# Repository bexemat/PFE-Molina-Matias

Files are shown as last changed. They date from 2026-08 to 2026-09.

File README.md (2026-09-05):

# Proyecto Final de Estudios (PFE) - Ingeniería en Mecatrónica (UNCUYO)

### Integración de Sistema de Visión Artificial y Planificación Dinámica de Trayectorias para una Celda de Clasificación Pick-and-Place

* **Autor:** Matías Exequiel Molina
* **Director:** Eric Sanchez
* **Institución:** Universidad Nacional de Cuyo - Facultad de Ingeniería
* **Año:** 2026

---

## 📌 Resumen del Proyecto

Este trabajo constituye una evolución técnica y funcional del manipulador paralelo de 3 GDL desarrollado previamente por Agüero y Lezcano. Transforma una maqueta experimental estática en una celda de manufactura orientada a estándares industriales, capaz de interceptar y clasificar piezas en movimiento continuo sobre una cinta transportadora mediante visión artificial en tiempo real y arquitectura de software distribuida.

### Puntos Clave de la Reingeniería
* **Control Embebido Determinista (Firmware C / FreeRTOS):** Migración de la cinemática inversa analítica y del planificador de trayectorias quínticas ($C^2$) hacia la FPU del microcontrolador STM32F446RE, desacoplando el lazo de control del tráfico serial en ROS 2. Lazo de movimiento determinista a 100 Hz (`mControlTask`) con PWM generado por hardware (TIM2, TIM3, TIM13) y lectura de encoders magnéticos absolutos AS5600 (12 bits) vía I2C a 400 kHz con multiplexor TCA9548A.
* **Percepción Visual en Tiempo Real (ROS 2 / OpenCV):** Estimación determinista de la velocidad lineal de avance mediante compuertas espaciales fijas ($\Delta Y = 70.0\text{ mm}$) a 30 FPS. Clasificación geométrica de piezas (Cubo vs. Cono) invariante a la rotación mediante el análisis combinado de *Extent* y relación de envolventes (*Rect Ratio*).
* **Supervisión y Orquestación:** Máquina de estados en ROS 2 con compensación temporal de magnetización ($T_{anticipo} = 0.15\text{ s}$), verificación en lazo cerrado de posición de reposo ($\pm2.0\text{ mm}$), despegue vertical puro ($Z_{lift} = 125.0\text{ mm}$) para suprimir fuerzas cortantes y retorno rápido evasivo ante fallos de retención.
* **Mecánica y Hardware:** Unión por chavetero mecanizada en los ejes de los motores paso a paso y engranajes impresos en 3D para neutralizar holguras y deslizamiento torsional. Acondicionamiento de pares trenzados blindados en el bus I2C (SCL/GND y SDA/VCC) para suprimir interferencias electromagnéticas. Integración de una cinta transportadora a escala diseñada en CAD (SolidWorks).

---

## 🛠️ Especificaciones Técnicas

* **Sistema Operativo:** Ubuntu 22.04 LTS (Jammy Jellyfish)
* **Middleware Robótico:** ROS 2 Humble Hawksbill & micro-ROS (XRCE-DDS serial @ 115200 baudios)
* **Herramientas de Firmware:** STM32CubeIDE v1.14+, FreeRTOS v10.3, ARM GCC Toolchain
* **Hardware de Control:** STM32 Nucleo-F446RE, 3x Controladores Pololu DRV8825 (configurados a 1/8 de micropaso)
* **Sensores:** 3x Encoders magnéticos absolutos de 12 bits AS5600 (I2C @ 400 kHz), Multiplexor TCA9548A
* **Visión:** Cámara Cenital HD 720p @ 30 FPS conectada mediante symlink persistente V4L2

---

## 📁 Estructura del Repositorio

```text
robot_workspace/
├── Firmware/                      # Proyecto STM32CubeIDE (C / FreeRTOS / micro-ROS)
│   ├── Core/
│   │   ├── Inc/                   # kinematics.h, trajectory_planner.h, motors.h, main.h, etc.
│   │   └── Src/                   # kinematics.c, trajectory_planner.c, tasks.c, main.c, etc.
│   └── micro_ros_stm32cubemx_utils/
├── ros2_ws/                       # Workspace de ROS 2 Humble
│   └── src/
│       ├── extra_interfaces/      # Mensajes personalizados ROS 2 (Trama.msg)
│       ├── robot_bringup/         # Archivos de lanzamiento consolidado (robot.launch.py)
│       └── robot_control/         # Paquete de control, visión y GUI
│           ├── gui/               # Interfaz V1 (robot_ui_node) y widgets Matplotlib
│           ├── gui_pickAndPlace_Final/ # Interfaz V2 continua (robot_ui_node_2) y FSM
│           ├── orchestrator/      # Nodo puente orquestador (publisher.py)
│           ├── planning/          # Herramientas auxiliares de planificación
│           └── vision/            # Nodo de visión OpenCV y scripts de calibración
├── Informe/                       # Documento formal del PFE en LaTeX (.tex) y bibliografía (.bib)
└── README.md

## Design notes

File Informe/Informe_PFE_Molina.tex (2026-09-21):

\documentclass[12pt, a4paper]{report}

% Paquetes esenciales
\usepackage[utf8]{inputenc}
\usepackage[spanish, es-tabla, es-nodecimaldot, es-noshorthands]{babel}
\usepackage[T1]{fontenc}
\usepackage{graphicx}
\usepackage{amsmath, amssymb}
\usepackage{booktabs}
\usepackage{tabularx}
\usepackage{geometry}
\geometry{top=3cm, bottom=3cm, left=3cm, right=3cm}

% Manejo de enlaces y corte de URLs sin desbordar margen
\PassOptionsToPackage{hyphens}{url}
\usepackage{hyperref}
\hypersetup{
    breaklinks=true,
    colorlinks=true,
    linkcolor=primary,
    citecolor=secondary,
    urlcolor=accentblue
}

% Paquetes para evitar desbordes de margen (Overfull \hbox)
\usepackage{microtype}
\usepackage[htt]{hyphenat}

\usepackage{titlesec}
\usepackage{fancyhdr}
\usepackage{cite}
\usepackage{float}
\usepackage{subcaption}
\usepackage{tikz}
\usepackage{pgfplots}
\pgfplotsset{compat=1.18}
\usepackage{array}
\usepackage{xcolor}
\usetikzlibrary{calc, babel, shapes.geometric, arrows.meta, positioning, fit, backgrounds, shadows}

% Definición de paleta de colores institucional
\definecolor{primary}{RGB}{24, 43, 73}
\definecolor{secondary}{RGB}{70, 130, 180}
\definecolor{lightgray}{RGB}{248, 249, 251}
\definecolor{darkgray}{RGB}{50, 50, 50}
\definecolor{accentblue}{RGB}{2, 136, 209}
\definecolor{accentorange}{RGB}{245, 124, 0}
\definecolor{accentpurple}{RGB}{81, 45, 168}
\definecolor{accentgreen}{RGB}{56, 142, 60}
\definecolor{accentred}{RGB}{198, 40, 40}

% Estilo de títulos
\titleformat{\chapter}{\normalfont\huge\bfseries}{\thechapter.}{20pt}{\Huge}

\title{Integración de Sistema de Visión Artificial y Planificación Dinámica de Trayectorias para una Celda de Clasificación Pick-and-Place sobre una Plataforma Robótica Existente}
\author{Matías Exequiel Molina}
\date{2026}

\begin{document}

\begin{titlepage}
    \centering
    \vspace*{1cm}
    \Large Universidad Nacional de Cuyo \\
    \large Facultad de Ingeniería \\
    \vspace{1cm}
    \Huge \textbf{Proyecto Final de Estudios} \\
    \vspace{0.5cm}
    \large Ingeniería en Mecatrónica \\
    \vspace{2cm}
    \Huge \textbf{Integración de Sistema de Visión Artificial y Planificación Dinámica de Trayectorias} \\
    \vspace{1cm}
    \large \textit{Continuación y evolución del sistema robótico de Agüero y Lezcano} \\
    \vspace{2cm}
    \textbf{Alumno:} Matías Exequiel Molina \\
    \textbf{Director:} Eric Sanchez \\
    \vspace{2cm}
    Mendoza, Argentina \\
    2026
\end{titlepage}

% ==========================================
% 2ª CARILLA: RESUMEN / ABSTRACT
% ==========================================
\newpage
\thispagestyle{plain}
\begin{center}
    \vspace*{0.5cm}
    {\Large \textbf{Resumen}}
    \vspace{0.8cm}
\end{center}

El presente Proyecto Final de Estudios aborda la evolución, reingeniería e integración funcional de una celda de manufactura robotizada a escala para operaciones de clasificación tipo \textit{pick-and-place} dinámico sobre piezas en movimiento. Tomando como plataforma de partida un manipulador serial de 3 GDL con mecanismo de paralelogramo articulado de cuatro barras desarrollado en un proyecto precedente, se diseñó e incorporó una cinta transportadora motorizada independiente y se transformó la operación estática original en un lazo continuo gobernado por visión artificial y control embebido determinista.

Para superar las restricciones de la plataforma heredada, se llevó a cabo una intervención integral a nivel mecánico, electrónico y computacional. En el aspecto físico, se implementaron acoples con unión por chaveta mecanizada en los ejes motores y un esquema de par trenzado diferencial para restaurar la integridad del bus I2C de los encoders magnéticos AS5600. En el plano cinemático, se descartó el modelo previo basado en articulaciones virtuales de Denavit-Hartenberg, formulando una cinemática inversa geométrica directa libre de singularidades espaciales. Asimismo, se reestructuró la arquitectura de control migrando el cálculo analítico de trayectorias quínticas ($C^2$) y el lazo de velocidad \textit{feedforward} + P a 100~Hz directamente a la FPU del microcontrolador STM32F446RE bajo FreeRTOS, comunicándose mediante micro-ROS con el host de supervisión y una nueva interfaz gráfica interactiva en PyQt5.

La percepción cenital en OpenCV (30~FPS, espacio HSV) introduce un esquema de compuertas espaciales consecutivas sobre la cinta que estima la velocidad lineal de avance en tiempo real ($v_{\text{obj}}$) sin depender de la carga gráfica del supervisor, complementado con un algoritmo de discriminación geométrica invariante a la orientación (Cubo vs. Cono) mediante la relación de envolventes (\textit{Rect Ratio}). Un filtro analítico de factibilidad cinemática evalúa en tiempo de ejecución si el tiempo disponible de arribo satisface los límites dinámicos de aceleración del robot ($T_{\text{MIN\_ROBOT}}$), sincronizando la intercepción mediante una rutina de despegue vertical puro ($Z_{\text{lift}}$) que suprime esfuerzos de corte.

La validación experimental sobre la celda demostró una tasa de éxito del 100\% en modo estático ($N=23$), alcanzando un 77.1\% de efectividad en la captura dinámica y un 74.3\% de ciclo completo clasificado en régimen continuo ($N=35$, $\bar{v} = 75.9\text{ mm/s}$). El sistema demostró capacidad de intercepción exitosa hasta los $108.9\text{ mm/s}$, a partir de la cual el orquestador aborta preventivamente las trayectorias inviables preservando el sincronismo de los actuadores y garantizando la seguridad global de la celda.

\vfill
\noindent \textbf{Palabras clave:} Robótica de Manipulación, Pick-and-Place Dinámico, ROS 2, micro-ROS, FreeRTOS, Visión Artificial, Cinemática Inversa.

\newpage
\tableofcontents
\newpage

\chapter{Introducción}
\section{Contexto del Proyecto}
El presente Proyecto Final de Estudios (PFE) constituye una evolución técnica y funcional del manipulador serial de 3 GDL con mecanismo de paralelogramo articulado de cuatro barras para operaciones tipo ``pick-and-place'', desarrollado previamente por Emanuel Agüero y Agustín Lezcano \cite{bib:aguero}. El sistema original ya integraba ROS 2 como estándar de comunicación, una base sólida que este proyecto retoma y potencia para transformar el prototipo en una celda de manufactura más estructurada, escalable y alineada con las buenas prácticas de la ingeniería de software y control embebido.

\section{Evolución, Diagnóstico y Reingeniería del Sistema}
La motivación principal para dar continuidad al proyecto desarrollado por Agüero y Lezcano surgió de la necesidad de evolucionar el prototipo original. El sistema heredado ya integraba clasificación por visión artificial para la manipulación de elementos comerciales, tales como rodamientos, tuercas, tornillos y llaves fijas. Sin embargo, la operación original se limitaba a un enfoque completamente estático, recogiendo las piezas dispuestas directamente sobre una superficie fija de trabajo. El objetivo de este nuevo proyecto fue dar un salto cualitativo hacia el realismo de una celda de manufactura en operación continua, para lo cual se diseñó e incorporó una cinta transportadora física. Esto permitió migrar hacia un sistema dinámico capaz de interceptar los objetos en movimiento basándose íntegramente en la retroalimentación de la visión artificial.

Al recibir la maqueta física y el código fuente, la etapa inicial de relevamiento presentó una alta complejidad técnica, demandando una revisión exhaustiva fundamentada en los conceptos teóricos de robótica y sistemas embebidos de tiempo real \cite{bib:robotica, bib:micro}. El firmware original operaba sobre un archivo monolítico (\texttt{main.c}) con más de 1000 líneas de código. A nivel de software de alto nivel, si bien el nodo de supervisión en ROS 2 era funcional para sus desarrolladores originales, su operación carecía de una interfaz visual orientada al usuario. Debido a la complejidad en la estructura de los comandos y a la curva de aprendizaje inicial del ecosistema ROS 2, durante las primeras pruebas prácticas solo se logró aislar y replicar exitosamente el accionamiento básico del solenoide del efector final. Ante este escenario, y con el propósito de establecer una base sólida, comprensible y escalable para el desarrollo futuro y para futuros alumnos, se decidió realizar una reestructuración profunda.

El primer paso consistió en modularizar el firmware del microcontrolador y desarrollar desde cero una nueva Interfaz Gráfica de Usuario (GUI) interactiva. Esta interfaz se dotó de controles deslizantes para el posicionamiento angular directo de cada motor y comandos discretos para la secuencia de \textit{homing} y la sujeción magnética. El proceso de integración comenzó vinculando la telemetría de los sensores magnéticos de posición hacia la interfaz, lo que permitió observar en tiempo real el comportamiento cinemático al mover el brazo manualmente. Tras verificar esta lectura, se logró la correcta ejecución del \textit{homing} y el solenoide. Posteriormente, se implementó un nuevo tópico dedicado a la recepción de comandos articulares punto a punto (P2P), generando trayectorias con perfiles de velocidad trapezoidal. Esto marcó el primer hito de control autónomo del manipulador.

Sin embargo, durante la fase de validación de movimientos surgieron fallas intermitentes. Los motores Q2 (hombro) y Q3 (muñeca) presentaban vibraciones severas, y en ocasiones, el motor principal de elevación (Q2) perdía la tracción, girando en vacío al recibir una consigna. Para aislar el problema, se procedió a desmontar el brazo y enviar comandos a los motores desacoplados de la estructura, comprobando que el software y la electrónica operaban correctamente. La inspección física reveló dos problemas fundamentales: a nivel eléctrico, un cable de fase del motor Q3 presentaba cortes internos; y a nivel mecánico, existían deficiencias en los acoples de transmisión. Se comprobó que el engranaje impreso del motor Q3 había cedido ante el momento torsor, destruyendo el alojamiento de los prisioneros de fijación, mientras que el motor Q2 había estado operando únicamente por fricción.

Para solucionar esta falla estructural, se llevó a cabo una reingeniería de los acoples. Utilizando un torno y fresas para metal, se mecanizaron los ejes cilíndricos de los motores paso a paso para incorporar un sistema de unión por chaveta. Simultáneamente, se rediseñaron e imprimieron en 3D nuevos engranajes que incluyeran el chavetero, manteniendo la fijación por prisionero original pero trasladando el esfuerzo de torsión a la chaveta. Esta intervención mitigó sustancialmente el deslizamiento y las holguras rotacionales.

Una vez resueltas las fallas de transmisión mecánica, un desafío adicional surgió al integrar el control espacial mediante coordenadas cartesianas (X, Y, Z) en la nueva interfaz. Inicialmente, se empleó el modelo cinemático heredado, el cual utilizaba la convención de Denavit-Hartenberg (D-H) e introducía un eslabón y articulación virtual para modelar matemáticamente la restricción de paralelismo del efector impuesta por el mecanismo de cuatro barras. Sin embargo, la contrastación empírica reveló que esta simplificación no reflejaba con suficiente precisión la pose real del efector final, evidenciando discrepancias sensibles especialmente en la coordenada de altura (Z), la cual resultaba ser la variable más crítica y fácil de medir. Los intentos preliminares de mitigar este error mediante factores de corrección empíricos resultaron insatisfactorios, ya que la calibración convergía solo en regiones acotadas del espacio de trabajo y divergía significativamente en otras.

Tras una revisión de la literatura técnica \cite{bib:kattel}, se decidió descartar el modelo D-H virtualizado y adoptar una aproximación analítica basada en un método geométrico y trigonométrico directo, adaptado específicamente para la morfología de robots con mecanismo de paralelogramo articulado de cuatro barras. La implementación de este nuevo modelo de cinemática en el software resolvió las incongruencias espaciales sistemáticas. Si bien el sistema conserva un error de posicionamiento residual marginal, se determinó que este es atribuible a las tolerancias de fabricación, holguras de rodamientos e imperfecciones elásticas de las piezas impresas en 3D, resultando un desvío admisible para las exigencias de la tarea estipulada.

Finalmente, con la mecánica y la cinemática estabilizadas, se intentó implementar el seguimiento de trayectorias cartesianas continuas. Se configuró la GUI para enviar tramas de posición a intervalos de 10 ms, buscando la velocidad y reacción necesarias para una futura intercepción dinámica de objetos en la cinta. Sin embargo, el movimiento resultante del brazo era errático y presentaba fuertes vibraciones. Un análisis del flujo de datos determinó que la alta tasa de envío generaba un cuello de botella en el canal de comunicación serial entre el orquestador en la PC (ROS 2) y el microcontrolador (micro-ROS y FreeRTOS), provocando latencias y pérdida de paquetes. Como solución arquitectónica para asegurar un perfil de velocidad continuo y determinista, se tomó la decisión de suprimir el cálculo dinámico continuo del planificador en ROS 2 y migrar la totalidad del cálculo analítico de trayectorias al nivel embebido, aprovechando la Unidad de Punto Flotante (FPU) del STM32.

\section{Justificación y Objetivos}
La selección de este PFE se fundamenta en su capacidad para integrar de manera armónica las diversas áreas de la Mecatrónica. La intervención principal se ha centrado en una reingeniería integral: se ha migrado el control hacia una gestión distribuida mediante \textbf{micro-ROS} sobre el \textbf{STM32F446RE}, aplicando principios de código limpio y modular. Asimismo, se optimizó la supervisión mediante una nueva interfaz de control (GUI) intuitiva y se corrigieron deficiencias en la transmisión mecánica y la integridad de señales del bus I2C. Este trabajo reafirma la importancia de la mejora continua sobre plataformas experimentales existentes, consolidando el desarrollo inicial como un banco de ensayos funcional y versátil.

\subsection{Objetivo General}
Desarrollar e integrar el sistema de procesamiento de visión artificial y planificación dinámica de trayectorias para una celda de clasificación industrial a escala, utilizando como base el brazo robótico de 3 GDL existente y una cinta transportadora independiente, logrando la detección, seguimiento y manipulación de objetos en movimiento dentro del periodo operativo estipulado.

\subsection{Objetivos Específicos}
\begin{itemize}
    \item \textbf{Relevamiento y Diagnóstico:} Relevar la arquitectura de control, cinemática y estado actual del sistema robótico existente basándose en el informe técnico de Agüero y Lezcano.
    \item \textbf{Definición de Módulos:} Determinar formalmente qué componentes del firmware y hardware existentes se reutilizan de manera directa y cuáles requieren modificaciones para la nueva aplicación.
    \item \textbf{Procesamiento Digital de Imágenes:} Programar un sistema de visión artificial basado en OpenCV (operando en espacio de color HSV) para segmentar, clasificar objetos en categorías básicas y estimar su posición instantánea (X, Y) sobre la banda de transporte.
    \item \textbf{Desarrollo del Planificador Dinámico:} Diseñar e implementar un algoritmo en el controlador STM32 Nucleo capaz de estimar el punto de intercepción futuro en el espacio de trabajo, sincronizando el efector magnético con la velocidad de la cinta transportadora.
    \item \textbf{Validación del Prototipo:} Evaluar el desempeño global del sistema mediante métricas experimentales de tasa de éxito, repetibilidad y límites operativos de velocidad.
    \item \textbf{Supervisión Remota (Opcional):} Configurar de manera secundaria un nodo de comunicación vía ESP32 para el envío de alertas o visualización de estados en un panel local en Node-RED, supeditado al correcto funcionamiento del lazo principal de pick-and-place.
\end{itemize}

\chapter{Estado del Arte y Antecedentes}
\section{El Proyecto de Agüero y Lezcano}
Este PFE se basa en el desarrollo previo realizado por Agüero y Lezcano, quienes implementaron un manipulador serial de 3 GDL con paralelogramo articulado de cuatro barras con visión artificial utilizando YOLOv11n y comunicación vía ROS 2. Como se observa en la Figura~\ref{fig:pfe_anterior}, su trabajo sentó las bases cinemáticas y la primera aproximación a la visión artificial en la plataforma, proporcionando una estructura impresa en 3D que sirve como chasis funcional.

\begin{figure}[H]
    \centering
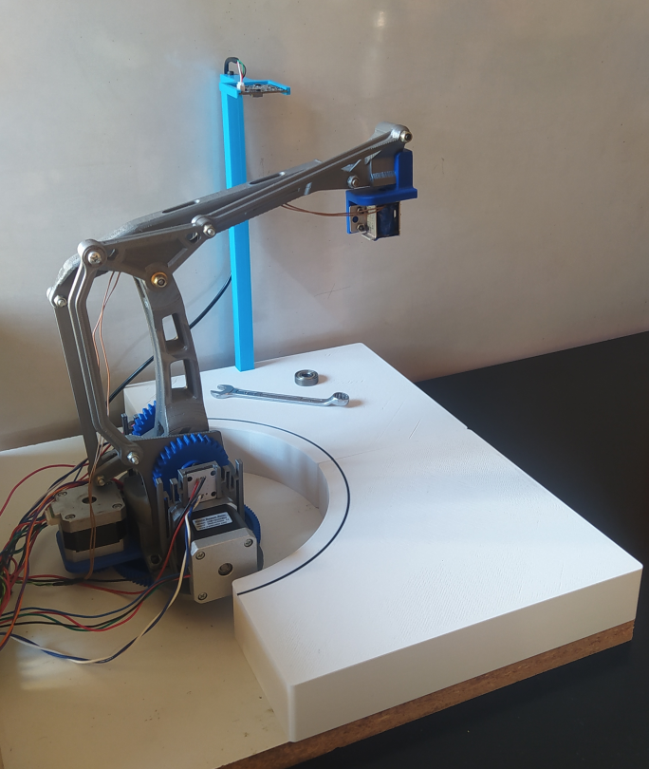
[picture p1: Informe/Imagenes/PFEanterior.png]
    
    \caption{PFE de Agüero y Lezcano: Manipulador serial de 3 GDL con mecanismo de cuatro barras y visión artificial.}
    \label{fig:pfe_anterior}
\end{figure}

\section{Manipuladores con mecanismo de cuatro barras en impresión 3D}
En el ámbito de la robótica de código abierto, proyectos como \textit{EezyBotArm} han democratizado el acceso a la manipulación robótica (ver Figura~\ref{fig:eezybotarm}). La tendencia actual en la comunidad académica es la migración de actuadores servomotores estándar hacia motores paso a paso con encoders absolutos (como los AS5600 integrados), permitiendo una precisión posicional superior en equipos de laboratorio. La integración de estas mejoras, junto con algoritmos de control de tiempo real, sitúa a este proyecto en el estado del arte de las celdas robotizadas a escala.

\begin{figure}[H]
    \centering
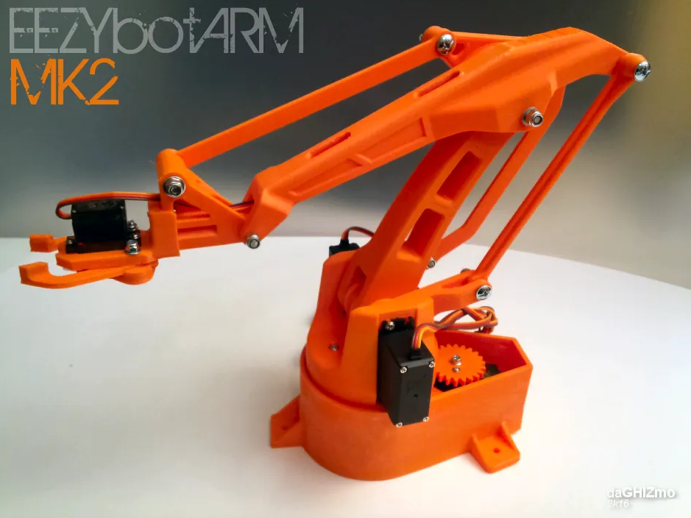
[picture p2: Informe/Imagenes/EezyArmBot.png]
    
    \caption{Manipulador serial de 3 GDL con mecanismo de paralelogramo de 4 barras.}
    \label{fig:eezybotarm}
\end{figure}

\section{Integración de micro-ROS en Sistemas Embebidos}
La evolución desde ROS 1 hacia ROS 2 ha introducido la capacidad de integrar nodos nativos directamente en microcontroladores mediante micro-ROS. Esta tecnología permite a los microcontroladores (como la familia STM32) participar como entidades de primera clase en el grafo de ROS, garantizando determinismo y reduciendo la latencia de capas intermedias. Su aplicación en sistemas robóticos distribuidos es un pilar fundamental en arquitecturas modernas de manufactura flexible.

\section{Planificación de Trayectorias Dinámicas en Pick-and-Place}
Los sistemas tradicionales de manipulación operan de manera estática: el objeto debe detenerse para ser sujetado. Sin embargo, la industria actual requiere la intercepción dinámica. Los algoritmos modernos combinan la estimación de velocidad del objeto (mediante visión artificial o encoders en las cintas) con la generación de trayectorias polinómicas (ej. quínticas) resueltas en tiempo real, permitiendo sincronizar la velocidad del efector final con la de la cinta transportadora en el momento exacto del agarre.

\begin{figure}[H]
    \centering
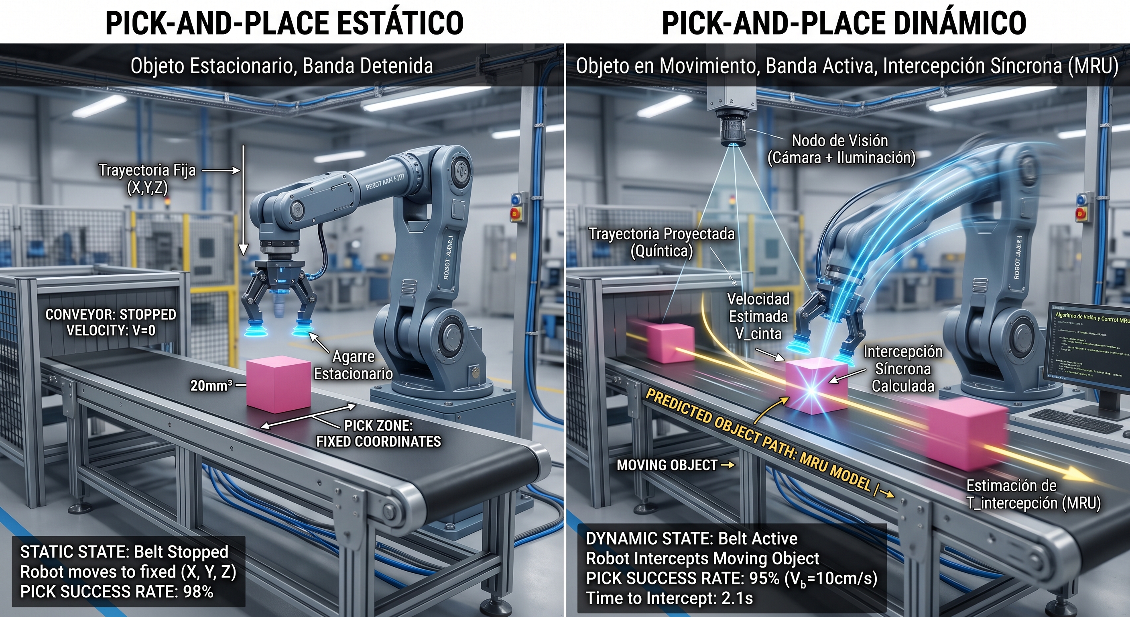
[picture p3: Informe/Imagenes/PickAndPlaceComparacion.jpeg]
    
    \caption{Comparativa entre Pick-and-Place estático y dinámico.}
    \label{fig:pick_and_place_comparacion}
\end{figure}

\chapter{Arquitectura del Sistema}
\section{Evolución de la Arquitectura de Software y ROS (Antes y Después)}
En el nivel de supervisión y alto nivel (ROS 2), la reingeniería abarcó la totalidad de los nodos de control para asegurar un enlace estructurado y de baja latencia con el microcontrolador:

\begin{itemize}
    \item \textbf{Nodo de Visión Artificial:} Mientras que la versión previa dependía de esquemas fragmentados, en este trabajo se desarrolló un nodo de visión propio y modular basado en sockets asíncronos (\texttt{VisionClient} y \texttt{VisionClientNode}), lo que permite una captura y conversión continua de coordenadas métricas de los objetos detectados.
    \item \textbf{Supresión del Planificador Continuo en ROS:} El nodo planificador continuo que anteriormente operaba en el espacio de ROS 2 fue suprimido de la computadora para las fases dinámicas, reubicando la generación analítica de la curva quíntica directamente en el firmware del STM32. Esto redujo drásticamente el tráfico serial y evitó las discontinuidades en los perfiles de velocidad.
    \item \textbf{Interfaz de Usuario (GUI):} La interfaz original presentaba restricciones operativas. Se programó un módulo gráfico interactivo completamente desde cero (\texttt{RobotUINode} y vistas en PyQt5) dotado de validación de límites articulares y cartesianos, comandos de homing, cinemática inversa y gestión centralizada de la parada por software (\texttt{E-Stop}).
    \item \textbf{Orquestador Central (\texttt{MinimalPublisher} / \texttt{publisher.py}):} El núcleo de coordinación fue modificado para actuar como compuerta de arbitraje y puente de hardware. Administra la máquina de estados del manipulador (\texttt{RobotState}) y la sincronización automática de secuencias operativas multi-segmento ($H \rightarrow A \rightarrow B \rightarrow H$) en conjunto con el servidor de visión.
\end{itemize}

En la Tabla~\ref{tab:comparativa_firmware} se resume la evolución de las características principales de la arquitectura del sistema.

\begin{table}[H]
\centering
\begin{tabularx}{\linewidth}{p{4.2cm} X X}
\toprule
\textbf{Dimensión} & \textbf{Versión Anterior} & \textbf{Versión Actual} \\
\midrule
Organización & Monolítica (\texttt{main.c}) & Modular por componentes \\
Trayectorias & Procesadas en PC & Planificadas en FPU del STM32 \\
Control & Acoplado a ROS & Distribuido (Tareas FreeRTOS) \\
\bottomrule
\end{tabularx}
\caption{Comparativa técnica del firmware.}
\label{tab:comparativa_firmware}
\end{table}

La migración hacia una arquitectura distribuida permitió la separación de los subsistemas en módulos independientes (\textit{kinematics}, \textit{trajectory\_planner}, \textit{microros\_callbacks}), facilitando el mantenimiento y la escalabilidad del sistema.

\section{Arquitectura Interna y Flujo de Datos}
La arquitectura de control y comunicación de la celda de manufactura se estructuró en tres niveles de abstracción: el nivel de supervisión y toma de decisiones en la PC host (ROS~2), el puente de comunicaciones de baja latencia (micro-ROS) y el nivel determinista de control embebido en tiempo real. Esta separación garantiza la regularidad en la inyección de señales físicas, un ancho de banda estable para la telemetría y un procesamiento computacional intensivo desacoplado del control directo del hardware.

El subsistema embebido implementado sobre la placa NUCLEO-F446RE desacopla la recepción asíncrona de comandos de alto nivel (vía micro-ROS sobre UART DMA) de la generación determinista de perfiles quínticos y el lazo de control articular ejecutado a 100~Hz bajo FreeRTOS. En la Figura~\ref{fig:mapa_conceptual_firmware} se describe el mapa conceptual global de interacción y acoplamiento funcional entre estos módulos.

\begin{figure}[H]
\centering
\begin{tikzpicture}[
    scale=0.88,
    transform shape,
    auto,
    >=Stealth,
    block/.style={rectangle, draw=black!80, fill=white, thick, text width=4.8cm, align=center, rounded corners=3pt, minimum height=1.2cm},
    hwblock/.style={rectangle, draw=teal!80!black, fill=teal!8, thick, text width=4.3cm, align=center, rounded corners=3pt, minimum height=1.2cm},
    rtosblock/.style={rectangle, draw=orange!80!black, fill=orange!10, thick, text width=4.8cm, align=center, rounded corners=3pt, minimum height=1.2cm},
    mathblock/.style={rectangle, draw=violet!80!black, fill=violet!10, thick, text width=4.3cm, align=center, rounded corners=3pt, minimum height=1.2cm},
    line/.style={draw=black!80, thick, -Latex},
    dashedline/.style={draw=blue!75!black, thick, dashed, -Latex},
    lbl/.style={fill=white, inner sep=2pt, font=\scriptsize, text=black!85, align=center}
]

    % Tronco central
    \node [block] (ros) {
        \textbf{ROS 2 / Supervisión (PC)}\\
        \scriptsize \texttt{/microROS/cmd} \quad \texttt{/planner/traj\_status}
    };
    
    \node [rtosblock, below=1.3cm of ros] (defaulttask) {
        \textbf{\texttt{tasks.c} (\texttt{defaultTask})}\\
        \scriptsize micro-ROS Executor + UART DMA
    };
    
    \node [rtosblock, below=1.4cm of defaulttask] (controltask) {
        \textbf{\texttt{tasks.c} (\texttt{mControlTask})}\\
        \scriptsize Lazo determinista a 100 Hz (10 ms)
    };

    \node [hwblock, below=1.4cm of controltask] (motors) {
        \textbf{\texttt{motors.c}}\\
        \scriptsize Lazo Feedforward + P\\
        \scriptsize Modulación PWM (TIM2, TIM3, TIM13)
    };

    % Columna derecha
    \node [mathblock, right=1.6cm of controltask] (planner) {
        \textbf{\texttt{trajectory\_planner.c}}\\
        \scriptsize Polinomio Quíntico $C^2$\\
        \scriptsize + Fallback Articular
    };
    
    \node [mathblock, below=1.4cm of planner] (kinematics) {
        \textbf{\texttt{kinematics.c}}\\
        \scriptsize FK analítico\\
        \scriptsize e IK trigonométrica
    };

    % Columna izquierda (ampliado a 2.2cm para dar margen limpio a las líneas y textos)
    \node [hwblock, left=2.2cm of motors] (sensors) {
        \textbf{\texttt{as5600\_tca9548.c}}\\
        \scriptsize Interrupción TIM7 + MUX I2C\\
        \scriptsize 3x Encoders AS5600 (400 kHz)
    };

    % 1. Conexiones verticales del tronco central
    \draw [line] (ros.south) -- node[lbl] {Trama UART DMA} (defaulttask.north);
    \draw [line] (defaulttask.south) -- node[lbl] {Cola \texttt{mid\_PositionQueue}} (controltask.north);
    \draw [line] (controltask.south) -- node[lbl] {$q_{ref}, \dot{q}_{ref}$} (motors.north);

    % 2. Conexiones horizontales con planificador y cinemática
    \draw [line] ([yshift=3.5mm]controltask.east) -- node[lbl, above] {Ciclo 10 ms} ([yshift=3.5mm]planner.west);
    \draw [line] ([yshift=-3.5mm]planner.west) -- node[lbl, below] {$q_{cmd}, \dot{q}_{cmd}, \text{status}$} ([yshift=-3.5mm]controltask.east);

    \draw [line] ([xshift=-4mm]planner.south) -- node[lbl, left] {$P(t) \rightarrow \text{IK}$} ([xshift=-4mm]kinematics.north);
    \draw [line] ([xshift=4mm]kinematics.north) -- node[lbl, right] {IK / FK OK} ([xshift=4mm]planner.south);

    \draw [line] (sensors) -- node[lbl] {$q_{real}$} (motors);

 % 3. Telemetría AS5600: Entrada local a defaultTask (desde sensors)
    \draw [dashedline, rounded corners=6pt] (sensors.north) 
        -- ++(0, 1.8cm)
        -- node[rotate=90, above=6pt, midway, font=\scriptsize, text=black!85] {Telemetría 40 Hz} ++(0, 2.2cm) 
        |- ([yshift=-3mm]defaulttask.west);

    % 4. Flujo de traj_status local: mControlTask -> defaultTask
    \draw [dashedline, rounded corners=6pt] (controltask.west) 
        -- ++(-1.0cm, 0) 
        -- node[rotate=90, above=5pt, midway, font=\scriptsize, text=black!85] {\texttt{traj\_status}} ++(0, 2.2cm)
        |- ([yshift=3mm]defaulttask.west);

    % 5. ÚNICA línea de publicación desde defaultTask hacia ROS 2 con los dos tópicos
    \draw [dashedline, rounded corners=6pt] (defaulttask.west) 
        -- ++(-2.0cm, 0) 
        -- node[rotate=90, above=6pt, midway, font=\scriptsize, text=black!85, align=center] {
            Publica \texttt{/microROS/angles}\\
            y \texttt{/planner/traj\_status}
        } ++(0, 2.7cm)
        |- (ros.west);
\end{tikzpicture}
\caption{Mapa de interacción y acoplamiento funcional de los módulos del firmware.}
\label{fig:mapa_conceptual_firmware}
\end{figure}

\subsection{Nivel de Control Embebido (Firmware)}
Para garantizar la ejecución en tiempo real, el firmware del microcontrolador STM32F446RE fue estructurado sobre el sistema operativo FreeRTOS, configurado con un \textit{tick} base de $1\text{ ms}$ y una asignación de memoria dinámica (Heap) de 46 KB. El núcleo de movimiento del robot opera dentro de una tarea dedicada (\texttt{mControlTask}) con alta prioridad y una frecuencia de actualización periódica de 100 Hz ($10\text{ ms}$).

La delegación de la planificación de trayectorias al nivel embebido requirió el diseño de algoritmos de control que consideraran los límites dinámicos de los motores paso a paso:
\begin{itemize}
    \item \textbf{Desacople de Hardware:} Las señales PWM son generadas por los temporizadores TIM2, TIM3 y TIM13, mitigando fluctuaciones temporales provocadas por tareas de software. La lectura de los sensores absolutos AS5600 se estructuró mediante el temporizador TIM7 y un multiplexor I2C, capturando la posición articular de manera periódica.
    \item \textbf{Planificador en Dos Fases:} El algoritmo genera un perfil polinómico de quinto grado ($C^2$). Se limita la velocidad máxima exigida a los actuadores al $85\%$ de su capacidad física admisible (establecida en $1000\text{ Hz}$). Si la duración demandada exige violar este límite, el firmware recalcula la duración ajustándola a la cota mínima calculada en el microcontrolador ($t_{\text{min\_fw}} \ge 0.60\text{ s}$).
    \item \textbf{Asentamiento Terminal:} Al finalizar la curva quíntica, se aplica un control local ($K_{p\_traj} = 3.5$) con tolerancia angular ($0.45^\circ$). Para evitar demoras provocadas por la inercia o la fricción estática de los eslabones impresos en 3D, se configuró una guarda de tiempo límite (\textit{timeout}) de $0.80\text{ s}$, tras el cual se corta la excitación PWM y se concluye la trayectoria informando el estado a la máquina superior.
\end{itemize}

\textbf{Descripción Técnica de los Diagramas de Firmware:}
\begin{itemize}
    \item \textbf{Bloques Principales (Figura~\ref{fig:diagrama_firmware}):} Ilustra el desacoplo temporal del sistema embebido. La tarea \texttt{defaultTask} gestiona la recepción asíncrona de comandos por micro-ROS y deposita las consignas en \texttt{mid\_PositionQueue}. La tarea de alta prioridad \texttt{mControlTask} corre a 100 Hz, consumiendo la cola para alimentar el lazo de control y la generación de pulsos PWM hacia los drivers A4988, mientras los encoders AS5600 proveen retroalimentación angular periódica.
    \item \textbf{Detalle 1 (Figura~\ref{fig:diagrama_firmware_detalle1}):} Detalla el flujo de interrupciones sobre la UART2 con DMA circular. El ejecutor \texttt{rclc} procesa las suscripciones de trayectoria cartesiana, consignas punto a punto articulares, control del solenoide y parada por software. Un temporizador interno a 40 Hz publica la telemetría articular sin saturar el bus serial.
    \item \textbf{Detalle 2 (Figura~\ref{fig:diagrama_firmware_detalle2}):} Muestra el flujo de cálculo en punto flotante (FPU). Al recibir una meta, se valida la cinemática inversa y se ejecuta un perfil quíntico $C^2$. Si el sistema entra en la fase terminal, transiciona a un lazo proporcional con ganancia $K_{p\_traj} = 3.5$ y una ventana de asentamiento de $0.80\text{ s}$ para absorber la fricción mecánica residual.
    \item \textbf{Detalle 3 (Figura~\ref{fig:diagrama_firmware_detalle3}):} Modela la capa de abstracción de hardware (HAL). Los temporizadores TIM2, TIM3 y TIM13 modulan la frecuencia en hercios para los motores paso a paso. En paralelo, el temporizador TIM7 dispara la máquina de estados no bloqueante por I2C que interroga cíclicamente al multiplexor TCA9548A y a los tres sensores magnéticos AS5600.
\end{itemize}

\begin{figure}[H]
    \centering
    \begin{tikzpicture}[
        font=\sffamily\small,
        >=Stealth,
        line width=0.8pt,
        box/.style={
            draw=black!85,
            fill=white,
            line width=1pt,
            align=center,
            inner sep=8pt,
            minimum width=4.8cm,
            drop shadow={opacity=0.15, shadow xshift=2pt, shadow yshift=-2pt}
        },
        queue/.style={
            cylinder,
            draw=black!85,
            fill=white,
            line width=1pt,
            shape border rotate=90,
            aspect=0.25,
            minimum width=3.4cm,
            minimum height=1.6cm,
            align=center,
            inner sep=2pt,
            drop shadow={opacity=0.15, shadow xshift=2pt, shadow yshift=-2pt}
        },
        lbl/.style={
            fill=black!15,
            text=black!90,
            inner sep=3.5pt,
            font=\sffamily\footnotesize,
            align=center
        }
    ]

        \node[box] (sensors) {Sensores 3x Encoders\\AS5600 y TIM7};
        \node[box, below=1.5cm of sensors] (microRos) {defaultTask micro-ROS};
        \node[queue, below=1.4cm of microRos] (queue) {mid\_PositionQueue};
        \node[box, below=1.5cm of queue] (mControl) {mControlTask Control y\\Cinematica};
        \node[box, below=1.4cm of mControl] (actuators) {Actuadores A4988 y\\Motores};

        \draw[->] (sensors) -- node[lbl] {Telemetria 40 Hz} (microRos);
        \draw[->] (microRos) -- node[lbl] {Encola Consigna Cartesiana} (queue);
        \draw[->] (queue) -- node[lbl] {Consume Datos 100 Hz} (mControl);
        \draw[->] (mControl) -- node[lbl] {Genera Pulsos PWM} (actuators);

        \coordinate (bypass) at ([xshift=1.2cm]sensors.east);

        \draw[->, rounded corners=12pt] 
            ([xshift=0.8cm]sensors.south) 
            -- (bypass |- sensors.south) 
            -- node[lbl, midway] {currentAngle} (bypass |- mControl.north) 
            -- ([xshift=1.0cm]mControl.north);

    \end{tikzpicture}
    \caption{Diagrama de bloques Firmware: Bloques Principales de Alto Nivel.}
    \label{fig:diagrama_firmware}
\end{figure}

\begin{figure}[H]
    \centering
    \begin{tikzpicture}[
        font=\sffamily\footnotesize,
        >=Stealth,
        line width=0.8pt,
        box/.style={
            draw=black!85,
            fill=white,
            line width=0.9pt,
            align=center,
            inner sep=5pt,
            minimum height=1.1cm,
            drop shadow={opacity=0.15, shadow xshift=1.5pt, shadow yshift=-1.5pt}
        },
        queue/.style={
            cylinder,
            draw=black!85,
            fill=white,
            line width=0.9pt,
            shape border rotate=90,
            aspect=0.25,
            minimum width=2.9cm,
            minimum height=1.1cm,
            align=center,
            inner sep=3pt,
            drop shadow={opacity=0.15, shadow xshift=1.5pt, shadow yshift=-1.5pt}
        }
    ]

        \node[box, text width=2.8cm] (uart) {UART2 DMA\\Circular};
        \node[box, text width=2.4cm, right=3.4cm of uart] (timer) {Timer 40 Hz};

        \node[box, text width=4.5cm, below=0.8cm of uart] (executor) {\texttt{rclc\_executor\_spin\_some}};
        \node[box, text width=3.4cm, below=0.8cm of timer] (pub) {Publicador:\\\texttt{/microROS/angles}};

        \draw[<->] (uart) -- (executor);
        \draw[->]  (timer) -- (pub);

        % Callback central alineado exactamente con el ejecutor
        \node[box, text width=3.0cm, below=1.3cm of executor] (cbP2p) {\texttt{p2p\_cmd\_callback}\\Joints Directos};
        
        % Callbacks laterales simétricos
        \node[box, text width=3.0cm, left=0.4cm of cbP2p] (cbCmd) {\texttt{cmd\_callback}\\Trama Cartesiana};
        \node[box, text width=3.0cm, right=0.4cm of cbP2p] (cbEstop) {\texttt{estop\_callback}\\Parada Emergencia};

        \node[queue, below=0.7cm of cbCmd] (queue) {\texttt{mid\_PositionQueue}};

        % Conexiones limpias y simétricas desde executor
        \draw[->, rounded corners=6pt] (executor.south) -- ++(0,-0.4) -| (cbCmd.north);
        \draw[->] (executor.south) -- (cbP2p.north);
        \draw[->, rounded corners=6pt] (executor.south) -- ++(0,-0.4) -| (cbEstop.north);

        \draw[->] (cbCmd) -- (queue);

    \end{tikzpicture}
    \caption{Diagrama de bloques Firmware Detalle 1: defaultTask y micro-ROS.}
    \label{fig:diagrama_firmware_detalle1}
\end{figure}

\begin{figure}[H]
    \centering
    \begin{tikzpicture}[
        font=\sffamily\footnotesize,
        >=Stealth,
        line width=0.8pt,
        box/.style={
            draw=black!85,
            fill=white,
            line width=0.9pt,
            align=center,
            inner sep=5pt,
            drop shadow={opacity=0.15, shadow xshift=1.5pt, shadow yshift=-1.5pt}
        },
        decision/.style={
            diamond,
            draw=black!85,
            fill=white,
            line width=0.9pt,
            align=center,
            inner sep=3pt,
            aspect=1.4,
            drop shadow={opacity=0.15, shadow xshift=1.5pt, shadow yshift=-1.5pt}
        },
        lbl/.style={
            fill=black!18,
            text=black!90,
            inner sep=2.5pt,
            font=\sffamily\scriptsize,
            align=center
        }
    ]

        \node[box, text width=3.8cm] (init) {Bucle Control\\100 Hz 10 ms};
        \node[decision, text width=2.4cm, below=0.8cm of init] (decCola) {Dato en Cola?};

        \node[box, text width=4.0cm, below right=0.9cm and 0.2cm of decCola] (trajStart) {\texttt{TrajectoryPlanner\_StartCtraj}\\IK + t\_min\_fw};

        \node[decision, text width=2.8cm, below=2.8cm of decCola] (decActiva) {Trayectoria\\Activa?};

        \node[box, text width=3.6cm, below left=1.0cm and 0.4cm of decActiva] (trayQuintica) {Trayectoria Quintica C2 +\\Asentamiento};
        \node[decision, text width=2.2cm, below right=0.9cm and 0.5cm of decActiva] (decP2P) {Modo P2P?};

        \node[box, text width=3.0cm, below=1.0cm of trayQuintica] (ctrlPd) {Lazo Feedforward + P\\Kp=3.5};
        \node[box, text width=2.5cm, below=1.0cm of decP2P] (p2pRamp) {\texttt{updateP2PRamp}};

        \node[box, text width=3.0cm, below=1.0cm of decActiva |- ctrlPd.south] (stepper) {\texttt{Stepper\_SetSpeed}\\Hz};

        \draw[->] (init) -- (decCola);
        \draw[->] (decCola.east) to[out=-30, in=90] node[lbl, pos=0.35] {Si} (trajStart.north);
        \draw[->] (decCola.west) to[out=210, in=150] node[lbl, midway] {No} (decActiva.north west);
        \draw[->] (trajStart.south) to[out=-90, in=30] (decActiva.north east);
        \draw[->] (decActiva.south west) to[out=210, in=90] node[lbl, midway] {Si} (trayQuintica.north);
        \draw[->] (decActiva.south east) to[out=-30, in=90] node[lbl, midway] {No} (decP2P.north);
        \draw[->] (trayQuintica) -- (ctrlPd);
        \draw[->] (decP2P) -- node[lbl, midway] {Si} (p2pRamp);
        \draw[->] (ctrlPd.south)  to[out=-90, in=120] ([xshift=-0.7cm]stepper.north);
        \draw[->] (p2pRamp.south) to[out=-90, in=60]  ([xshift=0.7cm]stepper.north);

    \end{tikzpicture}
    \caption{Diagrama de bloques Firmware Detalle 2: mControlTask y Planificador Quíntico.}
    \label{fig:diagrama_firmware_detalle2}
\end{figure}

\begin{figure}[H]
    \centering
    \begin{tikzpicture}[
        font=\sffamily\footnotesize,
        >=Stealth,
        line width=0.8pt,
        box/.style={
            draw=black!85,
            fill=white,
            line width=0.9pt,
            align=center,
            inner sep=4pt,
            text width=3.8cm,
            minimum height=1.05cm,
            drop shadow={opacity=0.15, shadow xshift=1.5pt, shadow yshift=-1.5pt}
        }
    ]

        \node[box] (c1r1) at (0, 0)       {Frecuencia de Paso Hz};
        \node[box] (c2r1) at (4.6, 0)     {Timer TIM7 IT};
        \node[box] (c3r1) at (9.2, 0)     {Comando Electroiman};

        \node[box] (c1r2) at (0, -1.6)   {TIM13 Q1, TIM2 Q2,\\TIM3 Q3};
        \node[box] (c2r2) at (4.6, -1.6) {Multiplexor I2C\\TCA9548A};
        \node[box] (c3r2) at (9.2, -1.6) {GPIO PC3 MOSFET\\+ PC7 LED};

        \node[box] (c1r3) at (0, -3.2)   {Drivers A4988\\1/8 Micropasos};
        \node[box] (c2r3) at (4.6, -3.2) {3x Sensores AS5600};

        \node[box] (c1r4) at (0, -4.8)   {Motores Paso a Paso\\NEMA};
        \node[box] (c2r4) at (4.6, -4.8) {{\scriptsize\texttt{motor1/2/3.currentAngle}}};

        \draw[->] (c1r1) -- (c1r2);
        \draw[->] (c1r2) -- (c1r3);
        \draw[->] (c1r3) -- (c1r4);

        \draw[->] (c2r1) -- (c2r2);
        \draw[->] (c2r2) -- (c2r3);
        \draw[->] (c2r3) -- (c2r4);

        \draw[->] (c3r1) -- (c3r2);

    \end{tikzpicture}
    \caption{Diagrama de bloques Firmware Detalle 3: Periféricos y Hardware Físico.}
    \label{fig:diagrama_firmware_detalle3}
\end{figure}

\begin{table}[H]
\centering
\small
\begin{tabularx}{\linewidth}{|p{3.0cm}|p{2.1cm}|p{2.5cm}|X|}
\hline
\textbf{Parámetro / Macro} & \textbf{Valor} & \textbf{Módulo} & \textbf{Justificación y Criterio} \\
\hline
\texttt{configTOTAL\_}\linebreak\texttt{HEAP\_SIZE} & 46 KB & \texttt{FreeRTOS.h} & Memoria dinámica para stacks de tareas y buffers de micro-ROS. \\
\hline
\texttt{CONTROL\_LOOP\_}\linebreak\texttt{PERIOD} & 100 Hz (10 ms) & \texttt{tasks.c} & Periodo de cómputo del planificador quíntico y control. \\
\hline
\texttt{timer\_period} & 40 Hz (25 ms) & \texttt{tasks.c} & Telemetría angular sin saturar canal UART/DMA. \\
\hline
Bus I2C & 400 kHz & \texttt{main.c} & Muestreo de 3 encoders AS5600 vía TIM7 sin bloqueo. \\
\hline
\texttt{MAX\_V\_HZ} & 1000 Hz & \texttt{motors.h} & Límite a 1/8 micropaso para evitar pérdidas de paso. \\
\hline
\texttt{max\_freq\_safe} & 850 Hz (85\%) & \texttt{traj\_planner.c} & Margen del 15\% para control proporcional sin saturación. \\
\hline
\texttt{t\_min\_fw} & 0.60 s & \texttt{traj\_planner.c} & Cota temporal inferior del generador quíntico embebido. \\
\hline
\texttt{Kp\_traj} & 3.50 & \texttt{motors.c} & Ganancia proporcional de seguimiento y asentamiento. \\
\hline
\texttt{ANGLE\_}\linebreak\texttt{TOLERANCE} & $0.25^\circ$ / $0.45^\circ$ & \texttt{main.h} & Ventana de convergencia para corte de excitación PWM. \\
\hline
Timeout Asentamiento & 0.80 s & \texttt{traj\_planner.c} & Límite temporal para evitar demoras por fricción residual. \\
\hline
\end{tabularx}
\caption{Parámetros operativos y criterios de diseño del Firmware (STM32 / FreeRTOS).}
\label{tab:parametros_firmware}
\end{table}

\subsubsection{Estructura del Lazo Articular: Control Feedforward + P}
A diferencia de un esquema PID clásico puro donde la señal depende enteramente de la acumulación histórica del error, el seguimiento dinámico de las trayectorias cartesianas se rige por un esquema de prealimentación de velocidad (\textit{feedforward}) acoplado a una realimentación proporcional (P) de posición \cite{bib:craig}.

\begin{figure}[htbp]
\centering
\begin{tikzpicture}[
    auto,
    block/.style={draw=darkgray, fill=white, thick, rectangle, minimum height=1cm, minimum width=1.5cm, text centered},
    sum/.style={draw=darkgray, fill=white, thick, circle, inner sep=2pt},
    input/.style={coordinate},
    output/.style={coordinate},
    arr/.style={draw=darkgray, thick, -Latex}
]
    \node [input] (qd_in) at (0, 1.5) {};
    \node [input] (q_in) at (0, 0) {};
    
    \node [sum] (sum_err) at (1.6, 0) {$+$};
    \node [block] (kp) at (3.4, 0) {$K_{p\_traj}$};
    
    \node [sum] (sum_ff) at (5.2, 0) {$+$};
    
    \node [block, text width=2.5cm] (robot) at (7.8, 0) {Robot / Driver A4988};
    \node [output] (out) at (10.4, 0) {};
    
    \node [block, text width=2.4cm] (sensor) at (7.8, -1.5) {Encoder AS5600};

    \draw [arr] (qd_in) -- node[above, near start] {$\dot{q}_{ref}(t)$ (Feedforward)} ++(5.2, 0) -- (sum_ff);
    
    \draw [arr] (q_in) -- node[above] {$q_{ref}(t)$} (sum_err);
    \draw [arr] (sum_err) -- node[above] {$e(t)$} (kp);
    \draw [arr] (kp) -- (sum_ff);
    
    \draw [arr] (sum_ff) -- node[above] {$v_{cmd}(t)$} (robot);
    \draw [arr] (robot) -- node[above] {$q(t)$} (out);
    
    \draw [arr] ($(robot.east)!0.5!(out)$) |- (sensor);
    \draw [arr] (sensor) -| node[pos=0.9, left] {$-$} (sum_err);

\end{tikzpicture}
\caption{Diagrama en bloques del lazo de control con prealimentación de velocidad (feedforward) y realimentación proporcional de posición.}
\label{fig:diagrama_control_ff}
\end{figure}

\paragraph{1. Modo Trayectoria Continua Quíntica (\texttt{TRAJ}): Velocidad Feedforward a 100 Hz}
En este modo, la referencia es un \textbf{vector dinámico instantáneo} $\mathbf{\dot{q}_{ref}(t)}$ (\texttt{qd\_ref} en $[^\circ/\text{s}]$) evaluado cada $\Delta t = 10\text{ ms}$ mediante la derivada analítica discreta de las consignas quínticas:
\begin{equation}
    \dot{q}_{ref}[i] = \frac{q_{current}[i] - q_{last}[i]}{\Delta t} \quad [^\circ/\text{s}]
\end{equation}
Esta señal entra directamente como prealimentación (\textit{feedforward}) al lazo implementado en \texttt{motors.c}:
\begin{equation}
    v_{cmd}(t) = \dot{q}_{ref}(t) + K_{p\_traj} \cdot \big(q_{ref}(t) - q_{real}(t)\big) \quad [^\circ/\text{s}]
\end{equation}
donde $K_{p\_traj} = 3.50$. La velocidad resultante se convierte en pulsos de excitación PWM para los controladores (A4988) considerando la reducción mecánica $i$ y la resolución a $1/8$ de micropaso ($1600\text{ pulsos/rev}$, equivalente a $\text{\texttt{DEG\_TO\_STEPS}} = 4.444\dots\text{ pulsos}/^\circ$):
\begin{equation}
    f_{PWM}\text{ [Hz]} = |v_{cmd}| \cdot \left(\frac{1600\text{ pulsos}}{360^\circ}\right) \cdot i
\end{equation}
Cotas de saturación:
\begin{itemize}
    \item \textbf{Corte por Velocidad Mínima:} Si $f_{PWM} < 1.0\text{ Hz}$ (\texttt{TRAJ\_CUTOFF\_FREQ\_HZ}), se desactiva la salida para evitar zumbidos residuales en los bobinados.
    \item \textbf{Límite Dinámico Superior:} $f_{PWM} \le 1000\text{ Hz}$ (\texttt{MAX\_V\_HZ}). El planificador restringe la velocidad pico de la curva al 85\% ($850\text{ Hz}$, \texttt{TRAJ\_MAX\_SAFE\_FREQ\_HZ}) para reservar un 15\% de margen al término proporcional.
\end{itemize}

\paragraph{2. Modo Punto a Punto (\texttt{P2P}): Velocidades de Régimen y Rampas}
En traslados manuales o rutinas de origen (\textit{homing}) gestionadas por temporizadores de hardware:
\begin{itemize}
    \item \textbf{Velocidad Nominal por Defecto:} $\text{\texttt{SPEED\_P2P\_DEFAULT\_HZ}} = 350.0\text{ Hz}$.
    \item \textbf{Velocidad Base de Arranque:} $\text{\texttt{MIN\_SPEED\_HZ}} = 150.0\text{ Hz}$.
    \item \textbf{Sincronización Multieje:} \texttt{startSynchronizedP2PMovement()} calcula la velocidad de régimen $v_{scaled} \in [280, 1000]\text{ Hz}$ para cada eje escalándola al tiempo del motor con mayor desplazamiento angular.
\end{itemize}

\subsubsection{Responsabilidad Específica de los Módulos del Firmware}

\paragraph{\texttt{main.c} --- Configuración del Microcontrolador y Recursos Base}
\begin{itemize}
    \item \textbf{Inicialización del Reloj:} Núcleo STM32F446RE a 180~MHz vía oscilador HSI acoplado al PLL ($M=8$, $N=180$, $P=2$).
    \item \textbf{Mapeo de Temporizadores PWM (Shield A4988):}
    \begin{itemize}
        \item \texttt{TIM13} (CH1) $\rightarrow$ Motor 1 (Cintura / Q1) --- 16 bits (ARR máx: $65535$).
        \item \texttt{TIM2} (CH2) $\rightarrow$ Motor 2 (Hombro / Q2) --- 32 bits (ARR máx: $4294967295$).
        \item \texttt{TIM3} (CH2) $\rightarrow$ Motor 3 (Muñeca / Q3) --- 16 bits (ARR máx: $65535$).
    \end{itemize}
    \item \textbf{Prevención de Overflow en ARR:} Como $\text{ARR} = (f_{timer}/f_{PWM}) - 1$, frecuencias menores a $2\text{ Hz}$ desbordarían registros de 16 bits. \texttt{Stepper\_SetSpeed()} satura a $65535$ y corta el pulso si $f < 2\text{ Hz}$.
    \item \textbf{Recursos FreeRTOS:} Instancia \texttt{mid\_PositionQueue} con capacidad para 4 consignas \texttt{CARTESIAN\_CMD\_t}.
\end{itemize}

\paragraph{\texttt{tasks.c} --- Concurrencia FreeRTOS y Transporte micro-ROS}
\begin{itemize}
    \item \textbf{\texttt{defaultTask} (Prioridad Normal --- Stack 8 KB):}
    Atiende micro-ROS vía UART2 DMA (115200 bps). Encola consignas cartesianas desde \texttt{/microROS/cmd}, procesa la parada por software en \texttt{/microROS/emergency\_stop} y publica ángulos a 40~Hz en \texttt{/microROS/angles}.
    \item \textbf{\texttt{mControlTask} (Alta Prioridad --- 100 Hz, Stack 4 KB):}
    Ejecutada periódicamente cada 10~ms con \texttt{vTaskDelayUntil()}. Desencola consignas de \texttt{mid\_PositionQueue}, evalúa \texttt{TrajectoryPlanner\_Update()}, modula el lazo Feedforward + P hacia \texttt{motors.c} y publica el estado en \texttt{/planner/traj\_status}.
\end{itemize}

\paragraph{\texttt{trajectory\_planner.c} --- Generador Quíntico y Fallback Articular}
Genera perfiles suaves con velocidad y aceleración nulas en extremos:
\begin{equation}
    s(\tau) = 10\tau^3 - 15\tau^4 + 6\tau^5, \quad \tau = \frac{t}{T} \in [0, 1]
\end{equation}
\begin{enumerate}
    \item \textbf{Fase de Arranque (\texttt{StartCtraj}):}
    Valida la cinemática inversa (IK) del destino y registra la pose articular inicial $\mathbf{q_{start}}$. Calcula el tiempo mínimo dinámico local evaluando la derivada pico ($1.875$):
    \begin{equation}
        t_{\text{min\_fw}} = \max\left(0.60\text{ s}, \, \max_{i \in \{1,2,3\}} \frac{1.875 \cdot \Delta q_i \cdot \text{DEG\_TO\_STEPS} \cdot i_{red}[i]}{850\text{ Hz}}\right)
    \end{equation}
    Nótese que este valor representa la cota inferior algorítmica del microcontrolador ante desplazamientos mínimos, diferenciándose de la guarda operativa del supervisor ($T_{\text{MIN\_ROBOT}}$) requerida para el traslado completo desde la guardia hasta la cinta.
    \item \textbf{Fase 1 ($\tau < 1.0$ --- Interpolación Quíntica y Fallback):}
    Interpola $P(t) = P_{start} + s(\tau)(P_{target} - P_{start})$. Si la recta cartesiana atraviesa una singularidad o excede el espacio de trabajo, \texttt{Kinematics\_IK()} falla y el firmware conmuta de forma continua al espacio articular:
    \begin{equation}
        q_{cmd}[i](t) = q_{start}[i] + s(\tau) \cdot \big(q_{target}[i] - q_{start}[i]\big)
    \end{equation}
    garantizando arribo a destino sin discontinuidades bruscas de velocidad ni interrupción del ciclo.
    \item \textbf{Fase 2 ($\tau \ge 1.0$ --- Asentamiento Terminal):}
    Mantiene $q_{target}$ con feedforward nulo. Supervisa que $|q_{target}[i] - q_{real}[i]| \le 0.45^\circ$. Si converge retorna \texttt{SUCCESS} (2); si expiran $0.80\text{ s}$ (\texttt{TRAJ\_SETTLING\_TIMEOUT\_S}) concluye por \texttt{TIMEOUT} (3).
\end{enumerate}

\paragraph{\texttt{kinematics.c}, \texttt{motors.c} y \texttt{as5600\_tca9548.c}}
\begin{itemize}
    \item \textbf{\texttt{kinematics.c}:} Geometría de cuatro barras: $L_1 = 77.0\text{ mm}$, $L_2 = 135.0\text{ mm}$, $L_3 = 147.0\text{ mm}$, $O_r = 25.49\text{ mm}$, $O_z = 40.87\text{ mm}$. Límites articulares de seguridad unificados estrictamente con el hardware: $Q_1 \in [-90^\circ, 90^\circ]$, $Q_2 \in [20^\circ, 157^\circ]$ (cota inferior requerida para alcanzar la cota lejana en $Y = -140.0\text{ mm}$), $Q_3 \in [-75^\circ, 25^\circ]$.
    \item \textbf{\texttt{motors.c}:} Ley $v_{cmd} = \dot{q}_{ref} + 3.5(q_{ref} - q_{real})$ traducida a pulsos PWM al 50\% de ciclo de trabajo.
    \item \textbf{\texttt{as5600\_tca9548.c}:} Muestreo I2C Fast-Mode (400 kHz) por TIM7 en Round-Robin ($1 \rightarrow 2 \rightarrow 3$) con filtro de rechazo $> 180^\circ$.
\end{itemize}

\subsubsection{Ciclo de Ejecución y Códigos de Estado}
Para asegurar la sincronización bidireccional entre el firmware embebido y los nodos de supervisión en ROS~2 (o interfaz gráfica de usuario), el planificador publica periódicamente su estado a través del tópico \texttt{/planner/traj\_status} empleando los códigos normalizados detallados en la Tabla~\ref{tab:codigos_traj_status}.

\begin{table}[H]
\centering
\small
\begin{tabularx}{\linewidth}{|c|l|X|}
\hline
\textbf{Código} & \textbf{Estado del Planificador} & \textbf{Criterio de Disparo en el Firmware} \\
\hline
$\mathbf{1}$ & \texttt{TRAJ\_STATUS\_RUNNING} & Maniobra en curso: interpolación quíntica ($\tau < 1.0$) o asentamiento ($\tau \ge 1.0$). \\
\hline
$\mathbf{2}$ & \texttt{TRAJ\_STATUS\_SUCCESS} & Conclusión exitosa con convergencia estática en los tres ejes ($\le 0.45^\circ$). \\
\hline
$\mathbf{3}$ & \texttt{TRAJ\_STATUS\_TIMEOUT} & Fin por expiración de guarda de asentamiento ($t_{settling} \ge 0.80\text{ s}$). \\
\hline
$\mathbf{-1}$ & \texttt{TRAJ\_STATUS\_ERROR\_IK\_START} & Rechazo inicial en \texttt{StartCtraj()}: punto destino inalcanzable. \\
\hline
$\mathbf{-2}$ & \texttt{TRAJ\_STATUS\_ERROR\_IK\_PATH} & Estado reservado ante fallas dinámicas críticas irrecuperables durante interpolación. \\
\hline
$\mathbf{-3}$ & \texttt{TRAJ\_STATUS\_ABORT\_ESTOP} & Cancelación forzada por parada de emergencia en \texttt{/microROS/emergency\_stop}. \\
\hline
\end{tabularx}
\caption{Códigos de sincronización publicados en \texttt{/planner/traj\_status}.}
\label{tab:codigos_traj_status}
\end{table}

\subsection{Puente de Comunicación (micro-ROS)}
El enlace entre el procesamiento de alto nivel y el control físico se realiza mediante el estándar DDS-XRCE. Una tarea dedicada (\texttt{defaultTask}), operando con prioridad normal y un \textit{stack} de 8 KB, administra el \textit{executor} de micro-ROS.

Esta capa intermedia gestiona la comunicación serial a través de una interfaz UART configurada con DMA circular, asegurando que la recepción asíncrona de datos no bloquee el control periódico de los motores. Para prevenir la sobrecarga del bus de datos y mantener la regularidad del sistema, el envío de telemetría articular hacia el orquestador se reguló mediante un temporizador de software interno que publica los mensajes a una frecuencia de 40 Hz (cada $25\text{ ms}$). Al recibir una trama cartesiana desde el supervisor, el \textit{callback} la deriva inmediatamente a una cola de mensajes no bloqueante (\texttt{mid\_PositionQueue}) para su consumo por la tarea de control.

En la Figura~\ref{fig:diagrama_global} se presenta la estructura global distribuida que interconecta la capa de supervisión en ROS 2 con el hardware embebido a través del agente micro-ROS.

\begin{figure}[H]
\centering
\begin{tikzpicture}[
    scale=0.76,
    transform shape,
    >=Stealth,
    font=\sffamily,
    bluebox/.style={rectangle, draw=cyan!70!blue!90, fill=cyan!8, thick, rounded corners=2pt, align=center, font=\scriptsize, inner sep=4pt, minimum height=0.72cm},
    darkbluebox/.style={rectangle, draw=blue!90!black, fill=blue!35!gray!25!black, text=white, thick, rounded corners=2pt, align=center, font=\footnotesize, inner sep=5pt, minimum height=1.15cm},
    yellowbox/.style={rectangle, draw=yellow!80!orange, fill=yellow!12, thick, rounded corners=2pt, align=center, font=\scriptsize, inner sep=4pt, minimum height=0.72cm},
    greenbox/.style={rectangle, draw=teal!80!green, fill=teal!8, thick, rounded corners=2pt, align=center, font=\scriptsize, inner sep=4pt, minimum height=0.78cm},
    greencyl/.style={cylinder, draw=teal!80!green, fill=teal!8, thick, shape border rotate=90, aspect=0.25, align=center, font=\scriptsize, inner sep=2pt, minimum height=0.95cm},
    groupframe/.style={draw=black!75, thick, rounded corners=3pt, fill=none},
    grouplbl/.style={font=\footnotesize\bfseries, text=black!85, fill=white, inner sep=2pt},
    greylbl/.style={draw=gray!50, fill=gray!15, inner sep=2pt, font=\tiny, text=black!90, rounded corners=1pt, align=center},
    line/.style={draw=black!80, thick, ->},
    biLine/.style={draw=black!80, thick, <->}
]

    % Supervisor
    \node [bluebox, text width=4.1cm] (vision) at (4.5, 0) {
        \textbf{vision\_detector\_node}\\(30 FPS)
    };
    \node [bluebox, text width=4.1cm] (ros2thread) at (4.5, -1.35) {
        \textbf{ROS2Thread} (rclpy Node)
    };
    \node [bluebox, text width=4.1cm] (ui) at (4.5, -2.7) {
        \textbf{robot\_ui\_node} (PyQt5)
    };
    \node [bluebox, text width=4.1cm] (sm) at (4.5, -4.05) {
        \textbf{PickAndPlaceSMV2} (FSM)
    };

    \begin{scope}[on background layer]
        \node [groupframe, fit=(vision) (sm), inner xsep=8pt, inner ysep=9pt] (box_supervisor) {};
        \node [grouplbl] at (box_supervisor.north) {Nivel Supervisor (PC / ROS 2)};
    \end{scope}

    % Bus y Puente
    \node [darkbluebox, text width=4.8cm] (bus) at (-4.2, -0.6) {
        \textbf{Bus de Tópicos ROS 2}\\
        {\scriptsize \texttt{/microROS/cmd}, \texttt{/p2p\_cmd}, \texttt{/homing}}\\
        {\scriptsize \texttt{/microROS/angles}, \texttt{/planner/traj\_status}}
    };
    \node [yellowbox, text width=4.3cm] (agent) at (-4.2, -2.85) {
        \textbf{micro-ROS Agent} (PC Host)
    };
    \node [yellowbox, text width=4.3cm] (dma) at (-4.2, -4.15) {
        \textbf{UART2 DMA Circular @}\\115200 bps
    };

    \begin{scope}[on background layer]
        \node [groupframe, fit=(agent) (dma), inner xsep=8pt, inner ysep=8pt] (box_bridge) {};
        \node [grouplbl] at (box_bridge.north) {Puente de Comunicación};
    \end{scope}

    % Embebido
    \node [greenbox, text width=4.7cm] (defaultTask) at (-3.8, -6.9) {
        \textbf{defaultTask} (micro-ROS Executor)
    };
    \node [greencyl, text width=3.8cm] (queue) at (-3.8, -9.0) {
        \textbf{mid\_PositionQueue}\\(Buffer Cartesiano)
    };
    \node [greenbox, text width=5.2cm] (hardware) at (3.8, -6.9) {
        \textbf{Hardware} (Timers PWM + A4988\\+ AS5600 + Electroimán)
    };
    \node [greenbox, text width=5.2cm] (mControlTask) at (3.8, -9.0) {
        \textbf{mControlTask} (100 Hz Loop)\\Kinematics + Trajectory Planner
    };

    \begin{scope}[on background layer]
        \node [groupframe, fit=(defaultTask) (queue) (hardware) (mControlTask), inner xsep=12pt, inner ysep=14pt] (box_embedded) {};
        \node [grouplbl] at (box_embedded.north) {Nivel Embebido (STM32F446RE / FreeRTOS)};
    \end{scope}

    \draw [line] (vision) -- node[greylbl] {Pose / Clase} (ros2thread);
    \draw [biLine] (ros2thread) -- node[greylbl] {Telemetría / Control} (ui);
    \draw [biLine] (ui) -- node[greylbl] {Eventos} (sm);
    \draw [biLine] (ros2thread.west) -- node[greylbl, above=2pt] {DDS Pub / Sub} (bus.east |- ros2thread.west);
    \draw [biLine] (bus.south) -- node[greylbl] {XRCE Bridge} (box_bridge.north);
    \draw [biLine] (agent) -- node[greylbl] {XRCE-DDS / Serial} (dma);
    \draw [biLine] ([xshift=-1.4cm]dma.south) -- node[greylbl, left=4pt, pos=0.5] {Transferencia\\Física} ([xshift=-1.8cm]defaultTask.north);
    \draw [line] (defaultTask) -- node[greylbl] {Consigna} (queue);
    \draw [line] (queue.east) -- node[greylbl, above=2pt] {Lectura 100 Hz} (mControlTask.west);
    \draw [line] ([xshift=-1.1cm]mControlTask.north) -- node[greylbl, left=2pt] {PWM / GPIO} ([xshift=-1.1cm]hardware.south);
    \draw [line] ([xshift=1.1cm]hardware.south) -- node[greylbl, right=2pt] {Feedback I2C} ([xshift=1.1cm]mControlTask.north);
    \draw [line] (hardware.west) -- node[greylbl, above=2pt] {Telemetría 40Hz} (defaultTask.east);

\end{tikzpicture}
\caption{Diagrama Global: Arquitectura Distribuida del Sistema.}
\label{fig:diagrama_global}
\end{figure}

\subsection{Nivel de Supervisión y Orquestación (ROS 2)}
El nivel superior opera en la computadora principal y concentra el procesamiento de visión artificial, el cálculo analítico de intercepción y la máquina de estados operativa. Al delegar la ejecución temporal de los motores al microcontrolador, el orquestador garantiza una toma de decisiones de alto nivel basada en condiciones de validación geométrica y temporal.
\begin{figure}[H]
    \centering
    \begin{tikzpicture}[
        block/.style={
            rectangle, 
            draw=black!85, 
            thick, 
            fill=white, 
            text width=5.2cm, 
            align=center, 
            minimum height=1.1cm,
            inner sep=8pt,
            drop shadow={shadow xshift=2pt, shadow yshift=-2pt, opacity=0.25}
        },
        arrow/.style={
            thick, 
            ->, 
            >=stealth
        },
        biarrow/.style={
            thick, 
            <->, 
            >=stealth
        },
        labelbox/.style={
            fill=gray!25, 
            font=\small, 
            text=black!90, 
            inner sep=3pt,
            align=center
        }
    ]

        \node[block] (vision) at (0, 0) {Modulo de Vision OpenCV 30\\FPS};
        
        \node[block] (ros) at (0, -2.2) {Lazo ROS 2 ros\_thread.py};
        
        \node[block] (gui) at (-3.5, -4.8) {Interfaz Grafica\\MainWindowV2};
        
        \node[block] (fsm) at (0, -7.4) {Maquina de Estados\\PickAndPlaceSMV2};

        \draw[arrow] (vision.south) -- node[labelbox] {Pose, Velocidad y Clase} (ros.north);
        
        \draw[biarrow] ([xshift=-1.2cm]ros.south) 
              to[out=-90, in=90] 
              node[labelbox, pos=0.45] {Senales Qt / Comandos} (gui.north);
        
        \draw[biarrow] (gui.south) 
              to[out=-90, in=90] 
              node[labelbox, pos=0.55] {Transiciones de Estado} ([xshift=-1.2cm]fsm.north);

        \draw[arrow] ([xshift=1.2cm]fsm.north) 
              to[bend right=45] 
              node[labelbox, pos=0.5] {send\_ctraj\_cmd /\\send\_magnet} ([xshift=1.2cm]ros.south);

    \end{tikzpicture}
    \caption{Diagrama de arquitectura y flujo de control del sistema.}
    \label{fig:diagrama_sistema}
\end{figure}

\subsubsection{Módulos Centrales de la Capa de Supervisión}

\paragraph{\texttt{vision\_detector\_node.py} --- Percepción Cenital, Velocidad y Clasificación}
Este nodo opera a 30 FPS en espacio de color HSV, asumiendo las siguientes responsabilidades analíticas:
\begin{itemize}
    \item \textbf{Adquisición y Calibración Métrica Cuadrática:} 
    Captura video a 640$\times$480 a 30 FPS. Tras segmentar el objeto en espacio HSV y filtrar ruido con clausuras y aperturas morfológicas, extrae el centroide $(c_x, c_y)$ mediante momentos geométricos. La coordenada longitudinal $Y$ sobre la cinta se obtiene mediante el polinomio calibrado:
    \begin{equation}
        Y_{robot}\text{ [mm]} = a \cdot c_x^2 + b \cdot c_x + c
    \end{equation}
    donde $a = 2.78487 \times 10^{-5}$, $b = 0.599751$ y $c = -193.5176$. El eje transversal de la cinta se encuentra posicionado en $X_{\text{FIXED}} = 215.0\text{ mm}$ y la altura de contacto en $Z_{\text{FIXED}} = 76.0\text{ mm}$.
    
    \item \textbf{Estimación Lineal de Velocidad por Compuertas Fijas:}
    Configura dos barreras espaciales transversales a la cinta: $Y_{G1} = -140.0\text{ mm}$ y $Y_{G2} = -70.0\text{ mm}$ ($\Delta Y = 70.0\text{ mm}$). Al cruzar la pieza $Y_{G1}$, registra la marca de tiempo de alta resolución $t_1$ (\texttt{time.perf\_counter()}) junto a la coordenada observada $y_1$. Al cruzar $Y_{G2}$, calcula la velocidad escalar determinista a partir del desplazamiento real observado:
    \begin{equation}
        v_{cinta} = \frac{y_2 - y_1}{t_2 - t_1} \quad [\text{mm/s}]
    \end{equation}
    publicando el vector $(v_{cinta}, Y_{actual}, flag_{medido})$ en el tópico \texttt{/detected\_object\_dynamic\_pose}.

    \item \textbf{Clasificación Morfológica Invariante a la Rotación (Cubo vs. Cono):}
    Evalúa la relación de cajas y densidad sobre el contorno en el cerrojo óptico ($-40.0 \le Y \le -20.0\text{ mm}$):
    \begin{equation}
        Ratio_{cajas} = \frac{\text{Área Bounding Box Rotado}}{\text{Área Bounding Box Recto}}, \quad Extent_{rot} = \frac{\text{Área Contorno}}{\text{Área Bounding Box Rotado}}
    \end{equation}
    Si la pieza rota ($Ratio_{cajas} < 0.85$) o su ocupación es densa ($Extent_{rot} > 0.85$), se clasifica como \textbf{Cubo} (\texttt{clase = 1}). De lo contrario, se clasifica como \textbf{Cono} (\texttt{clase = 2}).
\end{itemize}

\paragraph{\texttt{pick\_and\_place\_sm\_v2.py} --- Máquina de Estados y Factibilidad}
Orquesta las transiciones operativas mediante un autómata finito de estados continuos:
\begin{itemize}
    \item \textbf{Unificación Matemática del Filtro de Factibilidad:} 
    Ante la detección de un objeto a velocidad $v_{cinta}$, la máquina de estados calcula el tiempo disponible de arribo al punto de agarre ($Y_{target} = 120.0\text{ mm}$):
    \begin{equation}
        t_{disp} = \frac{Y_{target} - y_{actual}}{v_{cinta}} - T_{anticipo}
    \end{equation}
    donde $T_{anticipo} = 0.15\text{ s}$ compensa el retardo del solenoide. Simultáneamente, evalúa el tiempo mínimo demandado por el robot ($T_{\text{MIN\_ROBOT}}$) a partir de la cinemática inversa destino y la pose articular instantánea:
    \begin{equation}
        T_{\text{MIN\_ROBOT}} = \max\left(0.60\text{ s}, \, \max_{i \in \{1,2,3\}} \frac{1.875 \cdot |\Delta q_i| \cdot \text{DEG\_TO\_STEPS} \cdot i_{red}[i]}{850\text{ Hz}}\right)
    \end{equation}
    Para el trayecto completo nominal desde la guardia ($X=215, Y=-75, Z=100\text{ mm}$) hasta la intercepción ($X=215, Y=120, Z=76\text{ mm}$), este cálculo arroja $T_{\text{MIN\_ROBOT}} \approx 0.85\text{ s}$. Si la velocidad observada impone un tiempo disponible menor ($t_{disp} < T_{\text{MIN\_ROBOT}}$), la máquina de estados aborta preventivamente la intercepción. Esto evita que el manipulador inicie trayectorias inviables donde los motores perderían sincronismo al intentar acelerar por encima de $850\text{ Hz}$.
    
    \item \textbf{Manejo del Protocolo de Estados de Trayectoria:}
    Los códigos de retorno del firmware coordinan las transiciones: códigos de falla o parada por software ($\le -1$) desenergizan el electroimán y abortan el ciclo; el código de ejecución activa ($1$) mantiene la espera; y los códigos de éxito o fin de guarda ($2$ y $3$) habilitan el avance hacia el despegue vertical a $Z = 125\text{ mm}$, verificación óptica y descarga en contenedores clasificados.
\end{itemize}

\paragraph{\texttt{ros\_thread.py} y \texttt{robot\_ui\_node.py} --- Desacoplamiento Gráfico}
Aloja el ejecutor bloqueante \texttt{rclpy.spin()} en un hilo secundario (\texttt{QThread}), evitando degradar el renderizado visual de la GUI a 60 FPS. Mapea callbacks de tópicos ROS 2 hacia señales tipificadas de Qt: telemetría articular a 40 Hz (\texttt{feedback\_received}), eventos de finalización de trayectoria (\texttt{planner\_status\_received}), paquetes de tracking y velocidad (\texttt{vision\_dynamic\_target\_received}) y transmisión de fotogramas (\texttt{vision\_image\_received}). La interfaz principal integra la visualización de la clasificación en tiempo real, estimación de velocidad, monitor de estados y parada por software.

\paragraph{\texttt{publisher.py} --- Enrutador Puente de Hardware y Arbitraje}
Actúa como compuerta de arbitraje para mandos manuales y paradas de emergencia. Intercepta comandos de homing, movimientos articulares P2P y excitación del efector final provenientes de la interfaz gráfica. Si la bandera de seguridad por software \texttt{is\_estop\_active} está enclavada, bloquea de forma inmediata la publicación de tramas hacia micro-ROS, garantizando que el firmware no reciba consignas en estados inseguros.

\subsection{Diagramas de Secuencia e Interacción de la Celda}

\begin{figure}[H]
\centering
\begin{tikzpicture}[
    auto,
    node distance=0.9cm,
    font=\footnotesize,
    block/.style={rectangle, draw=darkgray, fill=white, thick, text width=3.8cm, text centered, rounded corners=3pt, minimum height=0.85cm},
    decision/.style={diamond, draw=primary, fill=lightgray, thick, text width=2.4cm, text centered, inner sep=1pt, aspect=1.8},
    hw/.style={rectangle, draw=accentgreen!80!black, fill=accentgreen!10, thick, text width=3.8cm, text centered, rounded corners=3pt, minimum height=0.85cm},
    warn/.style={rectangle, draw=accentred!80!black, fill=accentred!10, thick, text width=3.2cm, text centered, rounded corners=3pt, minimum height=0.8cm},
    line/.style={draw=darkgray, thick, -Latex}
]

    \node [block] (cam) {\textbf{Cámara Cenital (30 FPS)}\\Segmentación HSV y Tracking};
    \node [block, below=0.7cm of cam] (gates) {\textbf{Compuertas Espaciales}\\Estimación $v_{cinta}$ en $\Delta Y=70\text{ mm}$};
    \node [decision, below=0.8cm of gates] (fact) {$t_{disp} \ge T_{\text{MIN}}$?};
    
    \node [warn, right=1.2cm of fact] (abort) {\textbf{Estado 8: No Factible}\\Descarta pieza / Log GUI};
    \node [block, below=0.9cm of fact] (fsm) {\textbf{FSM Estado 4: Intercepción}\\Publica \texttt{/microROS/cmd}};
    
    \node [hw, below=0.8cm of fsm] (stm) {\textbf{STM32: \texttt{mControlTask} (100 Hz)}\\Curva Quíntica $C^2$ + Feedforward};
    \node [decision, below=0.8cm of stm] (status) {¿Código de estado?};
    
    \node [block, left=1.0cm of status] (lift) {\textbf{Estado 45: Lift $Z=125$}\\Elevación vertical pura};
    \node [warn, right=1.0cm of status] (err) {\textbf{Error / Aborto (-1,-2,-3)}\\Imán OFF / Retorno Guardia};
    
    \node [block, below=0.8cm of lift] (place) {\textbf{Estados 5 y 6: Place}\\Descarga en caja clasificada};

    \path [line] (cam) -- (gates);
    \path [line] (gates) -- (fact);
    \path [line] (fact) -- node[above] {No} (abort);
    \path [line] (fact) -- node[right] {Sí} (fsm);
    \path [line] (fsm) -- node[right] {Trama cartesiana} (stm);
    \path [line] (stm) -- (status);
    \path [line] (status) -- node[above] {2 ó 3} (lift);
    \path [line] (status) -- node[above] {$\le -1$} (err);
    \path [line] (lift) -- (place);
    \draw [line] (abort.north) |- (gates.east);
    \draw [line] (place.west) -| ++(-0.8cm,0) |- (fsm.west);

\end{tikzpicture}
\caption{Flujograma general de decisión, validación de factibilidad y ejecución de ciclo.}
\label{fig:diagrama_flujo_celda}
\end{figure}

\begin{table}[H]
\centering
\small
\begin{tabularx}{\linewidth}{|p{3.1cm}|p{2.2cm}|p{2.5cm}|X|}
\hline
\textbf{Parámetro / Variable} & \textbf{Valor} & \textbf{Módulo} & \textbf{Justificación y Criterio} \\
\hline
Tasa Captura Cenital & 30 FPS (33.3 ms) & \texttt{vision\_node.py} & Muestreo sin distorsión temporal. \\
\hline
Resolución Video & 640 $\times$ 480 px & \texttt{vision\_node.py} & Balance de resolución y baja latencia. \\
\hline
Compuertas $Y_1 \rightarrow Y_2$ & $-140 \rightarrow -70$ mm & \texttt{vision\_node.py} & Tramo fijo ($\Delta Y = 70$ mm) para medir velocidad. \\
\hline
Bloqueo Óptico & $[-40, -20]$ mm & \texttt{sm\_v2.py} & Fijación de clase en centro de lente sin oclusiones. \\
\hline
Extent / Rect Ratio & $\ge 0.85$ & \texttt{vision\_node.py} & Discriminación invariante a la orientación. \\
\hline
Meta Intercepción & $Y_{\text{pick}} = 120.0$ mm & \texttt{sm\_v2.py} & Posición nominal en espacio de trabajo. \\
\hline
\texttt{T\_MIN\_ROBOT} & Dinámico / 0.85 s & \texttt{sm\_v2.py} & Filtro analítico de descarte cinemático. \\
\hline
$T_{\text{anticipo}}$ & 0.15 s & \texttt{sm\_v2.py} & Compensación de retardo electromagnético. \\
\hline
\texttt{POS\_TOLERANCE} & $\pm 2.0$ mm & \texttt{sm\_v2.py} & Verificación en lazo cerrado para reposo en guardia. \\
\hline
Elevación ($Z_{\text{lift}}$) & 125.0 mm (0.6 s) & \texttt{sm\_v2.py} & Despegue en Z pura para evitar corte por fricción. \\
\hline
Failsafe Agarre & $Y > 135.0$ mm & \texttt{sm\_v2.py} & Detección de caída y retorno rápido (0.9 s). \\
\hline
\end{tabularx}
\caption{Parámetros de orquestación, visión y máquina de estados (ROS 2 / Python).}
\label{tab:parametros_supervisor}
\end{table}

\section{Protocolos de Interacción Operativos}
La arquitectura distribuida interconecta el nivel de supervisión en ROS 2 (Python / PyQt5) con la capa de control en la STM32F446RE (C / FreeRTOS / micro-ROS). A continuación se detallan los flujos de interacción para las principales funcionalidades operativas de la celda.

\subsection{Comando Punto a Punto Articular (P2P)}
El envío de consignas articulares directas permite posicionar el manipulador especificando los ángulos de cada articulación $(\theta_1, \theta_2, \theta_3)$:
\begin{itemize}
    \item \textbf{Capa de Supervisión (GUI):} El usuario ajusta los valores mediante los deslizadores o selectores numéricos en la pestaña de control manual de la interfaz gráfica.
    \item \textbf{Capa de Comunicación (ROS 2):} El método \texttt{send\_cmd} del hilo de comunicación empaqueta los ángulos en un mensaje del tipo \texttt{geometry\_msgs/msg/Point} y los publica a través del tópico \texttt{/microROS/p2p\_cmd}.
    \item \textbf{Capa Embebida (micro-ROS / Firmware):} El ejecutor del microcontrolador detecta el nuevo dato y ejecuta la función \texttt{p2p\_cmd\_callback}. Esta rutina invoca a \texttt{startSynchronizedP2PMovement()}, la cual calcula los perfiles de rampa de aceleración y velocidad sincronizada para los tres motores paso a paso.
\end{itemize}

\subsection{Secuencia de Referencia (Homing)}
La rutina de calibración y posicionamiento inicial al origen del robot se gestiona mediante el siguiente flujo:
\begin{itemize}
    \item \textbf{Capa de Supervisión (GUI):} Al presionar el botón de homing, la interfaz activa la señal correspondiente.
    \item \textbf{Capa de Comunicación (ROS 2):} Se publica un mensaje de tipo booleano (`True') a través del tópico \texttt{/microROS/homing}.
    \item \textbf{Capa Embebida (micro-ROS / Firmware):} El callback \texttt{homing\_callback} recibe la orden y ejecuta la función \texttt{doAllHoming()}. Esto desplaza de forma sincronizada cada articulación hacia su ángulo de referencia de homing configurado por hardware.
\end{itemize}

\subsection{Control del Efector Final (Electroimán / Solenoide)}
La manipulación y sujeción de piezas metálicas se rige por un control digital de estado:
\begin{itemize}
    \item \textbf{Capa de Supervisión (GUI):} El operador conmuta el estado del imán desde la interfaz, lo cual genera un mensaje de control.
    \item \textbf{Capa de Comunicación (ROS 2):} El nodo orquestador o la UI publican un mensaje tipo \texttt{std\_msgs/msg/Bool} en el tópico \texttt{/microROS/electroiman}.
    \item \textbf{Capa Embebida (micro-ROS / Firmware):} La función \texttt{electromagnet\_callback} procesa el mensaje y llama a \texttt{electromagnetOn()}, la cual conmuta físicamente los pines del GPIO y el LED indicador mediante la HAL de ST.
\end{itemize}

\subsection{Parada por Software y Alcance de Seguridad (E-Stop)}
El sistema implementa una respuesta prioritaria ante solicitudes de detención generadas desde la interfaz de control:
\begin{itemize}
    \item \textbf{Capa de Supervisión (GUI):} Al pulsar la parada en cualquier pestaña, se emite una orden prioritaria de detención.
    \item \textbf{Capa de Comunicación (ROS 2):} El enrutador puente (\texttt{publisher.py}) enclava la bandera \texttt{is\_estop\_active}, bloqueando de inmediato cualquier comando hacia el robot, y difunde un booleano (`True') a través de los tópicos \texttt{/microROS/emergency\_stop} y \texttt{/planner/emergency\_stop}.
    \item \textbf{Capa Embebida (micro-ROS / Firmware):} El callback \texttt{estop\_callback} aborta inmediatamente cualquier trayectoria activa en curso, conmuta el estado de los actuadores a \texttt{MOTOR\_ERROR} y detiene de forma forzosa la modulación PWM de los temporizadores para suprimir la excitación de los bobinados.
\end{itemize}

\textbf{Delimitación del Alcance de Seguridad:} Con rigor técnico, debe señalarse explícitamente que este mecanismo constituye una \textbf{parada de detención por software} implementada sobre la capa lógica de comunicación. Por tanto, \textbf{no debe considerarse como una parada de emergencia de seguridad funcional certificada bajo estándares industriales (tales como ISO 13849 o IEC 62061)}, puesto que depende de la disponibilidad del canal serial UART, la pila DDS de micro-ROS y el hilo supervisor en la PC host, careciendo de un circuito físico redundante y cableado directo de corte de energía (desconexión electromecánica de potencia).

\subsection{Planificación Cartesiana y Trayectorias Quínticas (ctraj)}
La ejecución de movimientos suaves en el espacio cartesiano utiliza las capacidades de cálculo local del microcontrolador:
\begin{itemize}
    \item \textbf{Capa de Supervisión (GUI):} Se ingresa la meta cartesiana $(X, Y, Z)$ y la duración deseada de la trayectoria, enviando una trama de datos estructurada.
    \item \textbf{Capa de Comunicación (ROS 2):} El método \texttt{send\_ctraj\_cmd} publica una estructura de tipo \texttt{extra\_interfaces/msg/Trama} a través del tópico \texttt{/microROS/cmd}.
    \item \textbf{Capa Embebida (micro-ROS / Firmware):} El callback \texttt{cmd\_callback} recibe la trama y encola los datos cartesianos de manera no bloqueante en \texttt{mid\_PositionQueue}. La tarea de alta prioridad \texttt{mControlTask} evalúa la cola, inicializa el planificador cartesiano mediante \texttt{TrajectoryPlanner\_StartCtraj()}, resuelve la cinemática inversa y ejecuta el control Feedforward + P en tiempo real sobre los motores.
\end{itemize}

\chapter{Desarrollos y Mejoras Implementadas}

\section{Evolución del Modelado Cinemático}

\subsection{Análisis del Modelo Anterior y Justificación del Cambio}
En la versión inicial del proyecto, la cinemática directa se abordó utilizando la convención de Denavit-Hartenberg (D-H) mediante matrices de transformación homogénea. Para la cinemática inversa, se empleó una aproximación geométrica con desacople cinemático que requirió la adición de un eslabón virtual ($L_4$) y un grado de libertad ficticio ($q_4$) para tratar al mecanismo como una cadena cinemática abierta. 

Si bien este método es funcional, la introducción de estos artificios matemáticos genera un modelo indirecto para un mecanismo con lazo cerrado de cuatro barras, lo que aumenta la complejidad analítica y el riesgo de divergencias en cálculo embebido.

\subsection{Nueva Aproximación: Método Geométrico Directo}
Tras una revisión de la literatura técnica \cite{bib:kattel}, se decidió descartar el modelo D-H virtualizado y adoptar una aproximación analítica basada en un método geométrico y trigonométrico directo, adaptado específicamente para la morfología de robots con mecanismo de paralelogramo articulado de cuatro barras. Este método mapea fielmente la morfología del manipulador a partir de las dimensiones físicas validadas mediante el ensamblaje en SolidWorks, eliminando las articulaciones virtuales y absorbiendo los desfases directamente en el cálculo del radio.

Los parámetros geométricos definitivos establecidos para esta versión son:
\begin{itemize}
    \item $L_1 = 77.00\text{ mm}$ (Altura de la base al hombro)
    \item $L_2 = 135.00\text{ mm}$ (Longitud del brazo principal)
    \item $L_3 = 147.00\text{ mm}$ (Longitud del antebrazo)
    \item $O_r = 25.49\text{ mm}$ (Offset radial del efector final)
    \item $O_z = 40.87\text{ mm}$ (Offset vertical del efector final)
\end{itemize}

\begin{figure}[H]
    \centering
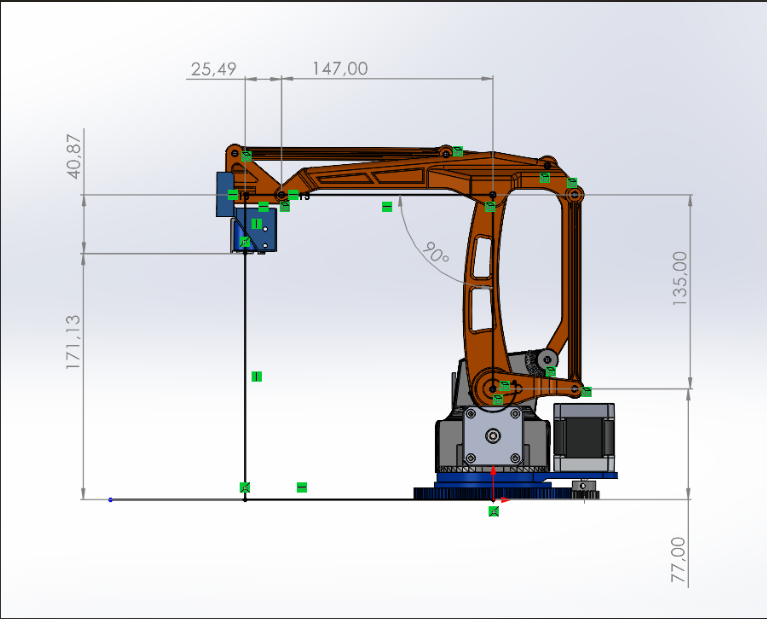
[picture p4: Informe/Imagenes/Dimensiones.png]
    
    \caption{Validación de parámetros geométricos y offsets del manipulador en SolidWorks.}
    \label{fig:cinematica_solidworks}
\end{figure}

\subsection{Cinemática Directa (FK)}
Conocidos los ángulos articulares absolutos $Q_1$, $Q_2$ y $Q_3$, la posición cartesiana $(X, Y, Z)$ del efector final se obtiene proyectando los eslabones sobre el plano de trabajo. El radio total $R$ incorpora de manera directa el offset radial:

\begin{equation}
    R = L_2 \cos(Q_2) + L_3 \cos(Q_3) + O_r
\end{equation}

A partir de este radio, las coordenadas espaciales resultan en:

\begin{align}
    X &= R \cos(Q_1) \\
    Y &= R \sin(Q_1) \\
    Z &= L_1 + L_2 \sin(Q_2) + L_3 \sin(Q_3) - O_z
\end{align}

\subsection{Cinemática Inversa (IK)}
Dada una coordenada cartesiana objetivo $(X, Y, Z)$, el ángulo de la base se determina por proyección directa en el plano horizontal:

\begin{equation}
    Q_1 = \text{atan2}(Y, X)
\end{equation}

Para resolver el mecanismo en el plano vertical, se define el desplazamiento hacia el nodo de la muñeca restando los offsets constructivos:

\begin{align}
    r &= \sqrt{X^2 + Y^2} - O_r \\
    z' &= Z + O_z - L_1
\end{align}

La distancia lineal $D$ entre la articulación del hombro y la muñeca resulta en:

\begin{equation}
    D = \sqrt{r^2 + (z')^2}
\end{equation}

Aplicando el Teorema del Coseno al triángulo físico formado por los eslabones $L_2$, $L_3$ y la distancia $D$, se obtienen los ángulos internos $\beta$ y $\gamma$:

\begin{align}
    \beta &= \arccos\left(\frac{D^2 + L_2^2 - L_3^2}{2 \cdot D \cdot L_2}\right) \\
    \gamma &= \arccos\left(\frac{D^2 + L_3^2 - L_2^2}{2 \cdot D \cdot L_3}\right)
\end{align}

Conociendo el ángulo de elevación de $D$ respecto a la horizontal, definido como $\alpha = \text{atan2}(z', r)$, los ángulos absolutos de las articulaciones quedan definidos por las siguientes expresiones, garantizando implícitamente la configuración ``codo arriba'':

\begin{align}
    Q_2 &= \alpha + \beta \\
    Q_3 &= \alpha - \gamma
\end{align}

\begin{figure}[H]
    \centering
    \begin{tikzpicture}[scale=1.5, >=stealth, font=\sffamily, thick]
        \def\Qtwo{55}
        \def\Qthree{-30}
        \def\Ltwo{3.0}
        \def\Lthree{3.2}
        
        \coordinate (O) at (0,0);
        \coordinate (E) at (\Qtwo:\Ltwo);
        \coordinate (W) at ($(E) + (\Qthree:\Lthree)$);
        
        \draw[->, gray, thin] (-0.5, 0) -- (5.5, 0) node[right, black] {$r$};
        \draw[->, gray, thin] (0, -0.5) -- (0, 4.0) node[above, black] {$z'$};
        
        \draw[dashed, blue!80!black, line width=1pt] (O) -- (W) node[midway, below=2pt] {$D$};
        \draw[orange!90!black, line width=2.5pt] (O) -- (E) node[midway, above left] {$L_2$};
        \draw[orange!90!black, line width=2.5pt] (E) -- (W) node[midway, above right] {$L_3$};
        
        \draw[dashed, gray, thin] (E) -- ++(2,0);
        
        \pgfmathanglebetweenpoints{\pgfpointorigin}{\pgfpointanchor{W}{center}}
        \pgfmathsetmacro{\alphaAngle}{\pgfmathresult}
        
        \draw[->, red!70!black] (0.7,0) arc (0:\Qtwo:0.7) node[midway, right=1pt] {$Q_2$};
        \draw[->, green!50!black] (1.4,0) arc (0:\alphaAngle:1.4) node[midway, right=1pt] {$\alpha$};
        \draw[->, purple] (\alphaAngle:2.0) arc (\alphaAngle:\Qtwo:2.0) node[midway, right=1pt] {$\beta$};
        
        \draw[->, red!70!black] ($(E) + (0.9,0)$) arc (0:\Qthree:0.9) node[midway, right=2pt] {$Q_3$};
        
        \pgfmathsetmacro{\gammaStart}{\Qthree + 180}
        \pgfmathsetmacro{\gammaEnd}{\alphaAngle + 180}
        \draw[<-, purple] ($(W) + (\gammaStart:0.6)$) arc (\gammaStart:\gammaEnd:0.6) node[midway, left=2pt] {$\gamma$};
        
        \filldraw[fill=white, draw=black, line width=1pt] (O) circle (0.06) node[below left=2pt] {Hombro $(0,0)$};
        \filldraw[fill=white, draw=black, line width=1pt] (E) circle (0.06) node[above=4pt] {Codo};
        \filldraw[fill=white, draw=black, line width=1pt] (W) circle (0.06) node[right=4pt] {Muñeca $(r, z')$};
        
    \end{tikzpicture}
    \caption{Diagrama trigonométrico de la Cinemática Inversa en el plano proyectado $r-z'$, mostrando las relaciones angulares de los eslabones.}
    \label{fig:diagrama_ik}
\end{figure}

\begin{figure}[H]
    \centering
    \begin{tikzpicture}[scale=1.5, >=stealth, font=\sffamily, thick]
        \def\alphaAng{35}
        \def\betaAng{45}
        \def\gammaAng{60}
        \def\Ltwo{3.5}
        
        \pgfmathsetmacro{\Lthree}{\Ltwo * sin(\betaAng) / sin(\gammaAng)}
        
        \pgfmathsetmacro{\Qtwo}{\alphaAng + \betaAng}
        \pgfmathsetmacro{\Qthree}{\alphaAng - \gammaAng}
        
        \coordinate (O) at (0,0);
        \coordinate (E) at (\Qtwo:\Ltwo);
        \coordinate (W) at ($(E) + (\Qthree:\Lthree)$);
        
        \draw[dashed, gray, thin] (-0.5,0) -- (4.5,0);
        \draw[dashed, gray, thin] ($(E) + (-1,0)$) -- ($(E) + (3,0)$);
        
        \draw[dashed, blue, line width=1pt] (O) -- (W) node[midway, below right] {$D$};
        \draw[dashed, blue, line width=1pt] (E) -- ($(E) + (\alphaAng:2.5)$) coordinate (E_parallel);
        
        \draw[orange!90!black, line width=2.5pt] (O) -- (E) node[midway, above left] {$L_2$};
        \draw[orange!90!black, line width=2.5pt] (E) -- (W) node[midway, below left] {$L_3$};
        
        \draw[->, green!50!black] (1.2,0) arc (0:\alphaAng:1.2) node[midway, right=1pt] {$\alpha$};
        \draw[->, purple] (\alphaAng:1.6) arc (\alphaAng:\Qtwo:1.6) node[midway, above right=-2pt] {$\beta$};
        
        \draw[->, green!50!black] ($(E) + (1.2,0)$) arc (0:\alphaAng:1.2) node[midway, right=1pt] {$\alpha$};
        \draw[<-, purple] ($(E) + (\Qthree:1.8)$) arc (\Qthree:\alphaAng:1.8) node[midway, right=1pt] {$\gamma$};
        \draw[->, red!70!black] ($(E) + (0.8,0)$) arc (0:\Qthree:0.8) node[midway, right=1pt] {$Q_3$};
        
        \filldraw[fill=white, draw=black, line width=1pt] (O) circle (0.06) node[below left] {Hombro $(O)$};
        \filldraw[fill=white, draw=black, line width=1pt] (E) circle (0.06) node[above=4pt] {Codo $(E)$};
        \filldraw[fill=white, draw=black, line width=1pt] (W) circle (0.06) node[below=4pt] {Muñeca $(W)$};
        
    \end{tikzpicture}
    \caption{Demostración visual del ángulo $Q_3$. Al trazar una línea paralela a $D$ desde el Codo, se observa por ángulos alternos internos que la inclinación absoluta del antebrazo es $Q_3 = \alpha - \gamma$.}
    \label{fig:demostracion_q3}
\end{figure}

\section{Reingeniería de acoples mecánicos (Unión por chavetero)}
Con el fin de resolver los problemas de deslizamiento y holgura torsional detectados en los acoples originales del sistema heredado, se llevó a cabo una reingeniería integral de la transmisión mecánica. Esta intervención consistió en el mecanizado de los ejes cilíndricos de los motores paso a paso para incorporar un alojamiento preciso, combinado con el rediseño y fabricación de los engranajes plásticos impresos en 3D para integrar una unión por chaveta. Esta solución proporciona una transmisión de torque rígida y mitiga de forma sustancial las desalineaciones angulares durante la operación continua de los ejes.

\begin{figure}[H]
    \centering
    \begin{subfigure}[b]{0.48\textwidth}
        \centering
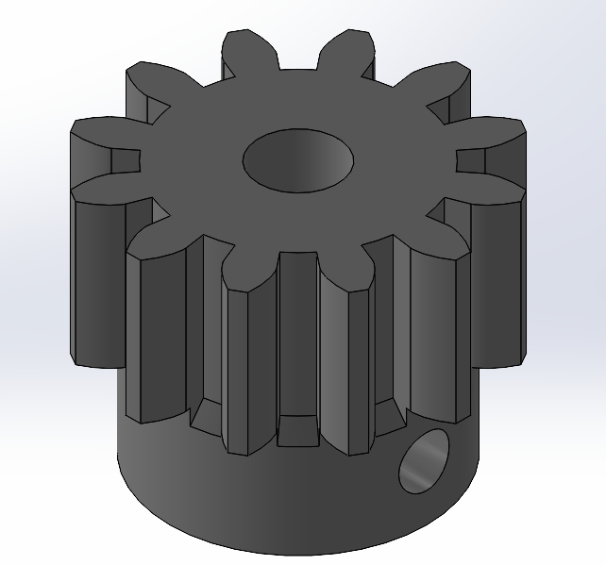
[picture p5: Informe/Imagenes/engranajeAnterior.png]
         
        \caption{Engranaje original con acople por fricción.}
        \label{fig:engranaje_anterior}
    \end{subfigure}
    \hfill
    \begin{subfigure}[b]{0.48\textwidth}
        \centering
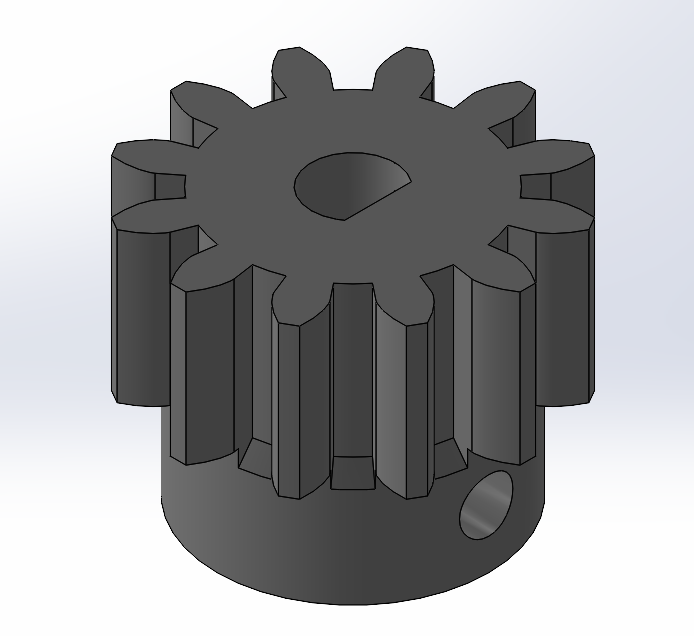
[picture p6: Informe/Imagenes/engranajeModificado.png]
         
        \caption{Engranaje impreso en 3D con unión por chaveta.}
        \label{fig:engranaje_chaveta}
    \end{subfigure}
    \caption{Comparativa de la reingeniería mecánica de engranajes.}
    \label{fig:reingenieria_mecanica}
\end{figure}

\section{Optimización de la integridad de señal en buses I2C}
Durante las pruebas iniciales del sistema, se detectaron anomalías e intermitencias en la comunicación con los sensores magnéticos basados en el protocolo I2C. Tras una revisión detallada del hardware, se identificó que el arnés de cables original presentaba una disposición física desfavorable: las líneas de reloj (\textit{SCL}) y de datos (\textit{SDA}) se encontraban trenzadas entre sí. Esta disposición propicia el acoplamiento capacitivo y la diafonía (\textit{cross-talk}) mutua entre señales digitales de alta frecuencia.

Para reducir el ruido electromagnético inducido y asegurar la estabilidad del bus, se rediseñó el tendido separando las líneas de señal y aplicando un esquema de par trenzado de referencia cerrada: se trenzó de manera independiente la línea de reloj con la referencia a tierra (\textit{SCL} con \textit{GND}), y la línea de datos con la alimentación (\textit{SDA} con \textit{VCC}). Esta modificación atenuó notablemente la susceptibilidad al ruido eléctrico generado por la conmutación de los motores paso a paso, logrando una transmisión de datos estable en el rango operativo del manipulador.

\section{Implementación del Nodo de Visión Artificial y Calibración}
Para dotar al sistema de la capacidad de percibir su entorno, se desarrolló un nodo de visión dedicado en ROS 2 (\texttt{VisionDetectorNode}) integrado con OpenCV, tomando como base arquitecturas de percepción aplicadas a brazos robóticos industriales \cite{bib:vo}. Este subsistema procesa el flujo de video en tiempo real de una cámara cenital conectada mediante un enlace persistente (\textit{symlink}). Dado que las condiciones de iluminación ambiental afectan de forma directa la segmentación cromática, el desarrollo contempló herramientas de calibración que favorecen la repetibilidad del sistema:

\subsection{Calibración Dinámica y Umbrales en Espacio HSV} 
Mediante una interfaz auxiliar interactiva (\texttt{calibrar\_hsv.py}) provista de controles deslizantes (\textit{trackbars}), es posible sintonizar de forma dinámica los rangos cromáticos del espacio de color HSV (Tono, Saturación y Valor). Esta transformación desacopla la información de color de la intensidad lumínica ambiental, aislando con alta fidelidad la silueta del objeto de prueba respecto al fondo de la cinta. 

Para purificar la máscara binaria resultante y eliminar los falsos positivos derivados del ruido del sensor o de reflejos en la superficie de la banda, se implementa una secuencia estricta de filtros morfológicos en dos etapas utilizando elementos estructurantes (\textit{kernels}):
\begin{enumerate}
    \item \textbf{Operación de Cierre (\textit{Morphological Close}):} Se aplica un kernel rectangular de $11\times11$ píxeles de manera iterativa (2 pasadas). Esta operación ejecuta una dilatación seguida de una erosión, lo que permite rellenar pequeños huecos, discontinuidades u oclusiones internas dentro de la silueta segmentada del objeto, asegurando un contorno cerrado y sólido.
    \item \textbf{Operación de Apertura (\textit{Morphological Open}):} A continuación, se aplica un kernel de menor tamaño de $5\times5$ píxeles. Consiste en una erosión seguida de una dilatación, destinada a suprimir el ruido disperso de fondo (pequeños puntos o motas aisladas que superan el umbral de color pero no pertenecen a una pieza válida).
\end{enumerate}

\subsection{Extracción del Centroide y Publicación en ROS 2}
Una vez aplicada la máscara de color y filtrado el ruido mediante operaciones morfológicas de apertura y cierre, el nodo analiza los contornos presentes en la escena. Al detectar el objeto de mayor área por encima del umbral establecido, se calculan los momentos espaciales de la imagen mediante la función \texttt{cv2.moments()}. A partir de los momentos de orden cero y uno, se obtiene la posición del centroide en píxeles $(cx, cy)$ aplicando las expresiones:

\begin{equation}
cx = \frac{M_{10}}{M_{00}}, \quad cy = \frac{M_{01}}{M_{00}}
\label{eq:centroide}
\end{equation}

donde $M_{00}$ representa el área total del objeto (momento de orden cero), y $M_{10}$ y $M_{01}$ son los momentos espaciales de primer orden respecto a los ejes $X$ e $Y$, respectivamente.

Esta posición en píxeles es convertida a coordenadas métricas utilizando el modelo polinómico cuadrático calibrado. Finalmente, el nodo empaqueta estas coordenadas espaciales en mensajes estándar de ROS 2 del tipo \texttt{geometry\_msgs/Point} y los transmite mediante dos publicadores: uno de flujo continuo para el modo estático y otro síncrono para las rutinas dinámicas del manipulador.

\subsection{Mapeo Métrico por Ajuste Polinómico (Píxel a Milímetro)} 
Para traducir las coordenadas de imagen desde el sistema de píxeles hacia unidades métricas reales en la base del robot, se implementó una rutina de calibración espacial. Este procedimiento se realiza posicionando el efector final a lo largo de la cinta transportadora mediante la cinemática directa (\textit{FK}) de la interfaz gráfica en un rango de $[-140, 140]\text{ mm}$ sobre el eje $Y$ del robot. 

Mediante el script \texttt{capturar\_punto.py}, se obtienen las coordenadas centroidales en píxeles de la cámara (correspondientes a la posición horizontal $x$ en la imagen) asociadas a cada posición real conocida. A partir de estos datos, recopilados en la Tabla~\ref{tab:obtension_puntos_calibracion}, se emplea el script de automatización \texttt{calcular\_polinomico.py}. Este programa interactivo procesa los pares empíricos aplicando un modelo de regresión por mínimos cuadrados mediante la función \texttt{np.polyfit()} de NumPy, resolviendo un polinomio de segundo orden de la forma $Y_{\text{robot}} = a \cdot X_{\text{px}}^2 + b \cdot X_{\text{px}} + c$. Su ejecución permite calcular con alta precisión los coeficientes empíricos que compensan los errores de curvatura y distorsión óptica de la lente cenital, garantizando linealidad métrica en todo el trayecto útil sobre la banda.

\begin{table}[H]
\centering
\small
\begin{tabular}{|c|c|c|}
\hline
\textbf{Punto N$^\circ$} & \textbf{$Y_{\text{real}}$ [mm]} & \textbf{Coordenada $X$ [píxeles]} \\ \hline
1  & -139.4 & 539.51 \\ \hline
2  & -119.7 & 512.61 \\ \hline
3  & -99.3  & 478.64 \\ \hline
4  & -79.4  & 445.67 \\ \hline
5  & -60.3  & 413.91 \\ \hline
6  & -40.0  & 383.16 \\ \hline
7  & -20.1  & 354.19 \\ \hline
8  &   0.3  & 318.16 \\ \hline
9  &  19.8  & 287.23 \\ \hline
10 &  40.1  & 250.50 \\ \hline
11 &  60.0  & 217.86 \\ \hline
12 &  79.8  & 184.59 \\ \hline
13 &  99.1  & 153.92 \\ \hline
14 & 119.8  & 122.78 \\ \hline
15 & 139.5  &  89.47 \\ \hline
\end{tabular}
\caption{Registro completo de adquisición de puntos experimentales para la calibración espacial ($N = 15$).}
\label{tab:obtension_puntos_calibracion}
\end{table}

\begin{figure}[H]
\centering
\begin{tikzpicture}
\begin{axis}[
    width=0.85\textwidth,
    height=6.5cm,
    xlabel={Coordenada Horizontal $X$ [píxeles]},
    ylabel={Posición Real $Y_{\text{FK}}$ [mm]},
    grid=major,
    grid style={dashed, gray!30},
    xmin=50, xmax=580,
    ymin=-160, ymax=160,
    legend pos=north west,
    font=\small
]

    % Curva de tendencia cuadrática superpuesta (Modelo del nodo de visión)
    \addplot[
        domain=74.91:553.78,
        samples=100,
        color=primary,
        thick,
        smooth
    ] {0.0000278487 * x^2 + 0.5997512673 * x -193.5175741780};
    \addlegendentry{Modelo Polinómico Cuadrático}

    % Puntos experimentales registrados en la Tabla (N = 15)
    \addplot[
        only marks,
        mark=*,
        mark size=2pt,
        color=accentred
    ] coordinates {
        (89.47, -140.63)
        (122.78, -120.41)
        (153.92, -100.22)
        (184.59, -79.89)
        (217.86, -60.16)
        (250.50, -40.28)
        (287.23, -20.86)
        (318.16, 0.34)
        (354.19, 20.14)
        (383.16, 40.37)
        (413.91, 60.20)
        (445.67, 79.57)
        (478.64, 99.60)
        (512.61, 120.25)
        (539.51, 139.48)
    };
    \addlegendentry{Puntos Experimentales N 15}

\end{axis}
\end{tikzpicture}
\caption{Curva de calibración polinómica $Y_{\text{FK}}$ frente a $X$ en píxeles, evidenciando la mitigación de la distorsión óptica.}
\label{fig:curva_calibracion_experimental}
\end{figure}

\subsection{Test Experimental y Análisis de Dispersión del Sistema de Visión}
Para cuantificar rigurosamente la precisión métrica del nodo de visión una vez implementado el ajuste polinómico cuadrático, se desarrolló una serie de pruebas sistemáticas directamente sobre la maqueta física de la celda, basándose en la captura de $N = 15$ puntos de control distribuidos longitudinalmente sobre la cinta transportadora.

\textbf{Metodología del Ensayo:} Utilizando la cinemática directa (FK) desde la interfaz gráfica de usuario (GUI), se posicionó de manera estática el efector final con un cubo de referencia patrón en marcas espaciadas cada $20.0\text{ mm}$ de forma sucesiva, abarcando todo el rango operativo de la cinta desde $Y = -140.0\text{ mm}$ hasta $Y = +140.0\text{ mm}$. En cada una de las 15 posiciones discretas, el nodo \texttt{VisionDetectorNode} procesó la imagen para estimar la coordenada cartesiana $\hat{Y}$ mediante el modelo polinómico, registrando el desvío residual absoluto $e_i = |\hat{Y}_i - Y_{\text{real}, i}|$.

\begin{table}[H]
\centering
\small
\begin{tabular}{|c|c|c|c|}
\hline
\textbf{Punto N$^\circ$} & \textbf{$Y_{\text{real}}$ [mm]} & \textbf{$Y_{\text{vision}}$ [mm]} & \textbf{Error Residual $e_i$ [mm]} \\ \hline
1  & -139.4 & -137.8 & 1.6 \\ \hline
2  & -119.7 & -118.0  & 1.7 \\ \hline
3 & -99.3  & -98.3  & 1.0 \\ \hline
4 & -79.4    & -79.2   & 0.2 \\ \hline
5 & -60.3 & -60.2  & 0.1 \\ \hline
6 & -40.0 & -39.6 & 0.4 \\ \hline
7 & -20.1 & -19.6 & 0.5 \\ \hline
8  & 0.3 & 0.5 & 0.2 \\ \hline
9  & 19.8 & 20.7  & 0.9 \\ \hline
10 & 40.1  & 40.6  & 0.5 \\ \hline
11 & 60.0    & 59.3   & 0.7 \\ \hline
12 & 79.8  & 79.5  & 0.3 \\ \hline
13 & 99.1 & 99.7 & 0.6 \\ \hline
14 & 119.8 & 118.7 & 1.1 \\ \hline
15 & 139.5 & 140.0 & 0.5 \\ \hline
\end{tabular}
\caption{Muestra representativa del test de dispersión del sistema de visión ($N = 15$ puntos muestreados cada $20\text{ mm}$).}
\label{tab:test_vision_dispersion}
\end{table}

\textbf{Análisis Estadístico de Dispersión y Errores:}
A partir de la serie completa de los 15 puntos registrados experimentalmente, se computaron los indicadores globales de desempeño del algoritmo de percepción:
\begin{itemize}
    \item \textbf{Error Medio (Bias):} $+0.41\text{ mm}$
    \item \textbf{Error Absoluto Medio (MAE):} $0.69\text{ mm}$
    \item \textbf{Raíz del Error Cuadrático Medio (RMSE):} $0.83\text{ mm}$
    \item \textbf{Desviación Estándar de Dispersión ($\sigma$):} $0.73\text{ mm}$
    \item \textbf{Error Máximo Residual:} $1.70\text{ mm}$
\end{itemize}

Los resultados cuantitativos demuestran que la dispersión del sistema de visión se mantiene dentro de una cota submilimétrica en la región central del campo visual y no supera $1.70\text{ mm}$ en los extremos del área de trabajo. Esta baja dispersión ($\sigma = 0.73\text{ mm}$) certifica la alta repetibilidad del nodo de visión y valida la suficiencia del modelo cuadrático para mitigar la distorsión óptica de la lente cenital, asegurando un posicionamiento altamente compatible con la tolerancia de agarre del efector magnético.

\subsection{Clasificación Geométrica de Objetos Invariante a la Rotación}
Para habilitar la capacidad de clasificación del sistema, se integró un algoritmo capaz de discriminar entre distintas geometrías de piezas que comparten el mismo color (en este caso, un cubo y un cono truncado de color rosa).

La discriminación basada únicamente en contornos básicos resultaba sensible ante sombras o variaciones de silueta. Inicialmente se evaluó el método del \textbf{Extent Rotado} (relación entre el área del objeto y su \texttt{minAreaRect}). No obstante, las pruebas experimentales demostraron que cuando el cubo ingresaba orientado en diagonal, el filtrado morfológico redondeaba sus esquinas, reduciendo su coeficiente Extent a valores cercanos a los del cono ($\approx 0.81$).

Para resolver este solapamiento y alcanzar una alta tasa de discriminación geométrica independiente de la orientación, se incorporó una segunda métrica basada en la \textbf{Relación de Cajas (Rect Ratio)}:

\begin{equation}
    \text{Rect Ratio} = \frac{A_{\text{rotada}}}{A_{\text{recta}}} = \frac{\text{Área } \texttt{minAreaRect}}{\text{Área } \texttt{boundingRect}}
\end{equation}

La lógica de decisión combinada opera evaluando la dispersión de área: si el cubo se encuentra rotado, su caja recta encierra una mayor proporción de fondo vacío, produciendo un \textit{Rect Ratio} inferior a $0.85$. Si la pieza transita alineada con la cinta, ambas cajas presentan áreas semejantes (\textit{Rect Ratio} $\approx 1.0$), instancia en la cual se evalúa su densidad mediante el \textit{Extent} (donde un cubo presenta valores sistemáticamente mayores a $0.85$). Este enfoque complementario otorga una clasificación geométrica confiable frente a distintas orientaciones de ingreso de la pieza.

\begin{figure}[H]
    \centering
    \begin{subfigure}[b]{0.48\textwidth}
        \centering
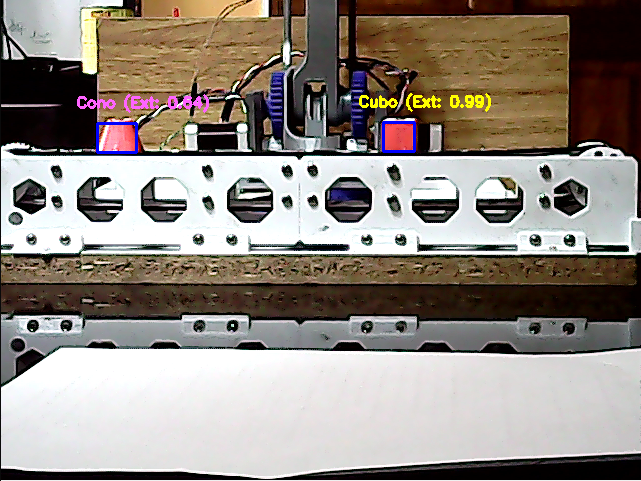
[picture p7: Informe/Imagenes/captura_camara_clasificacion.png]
         
        \caption{Vista de cámara con caja rotada (\texttt{minAreaRect}) y clasificación por Extent.}
        \label{fig:captura_clasificacion}
    \end{subfigure}
    \hfill
    \begin{subfigure}[b]{0.48\textwidth}
        \centering
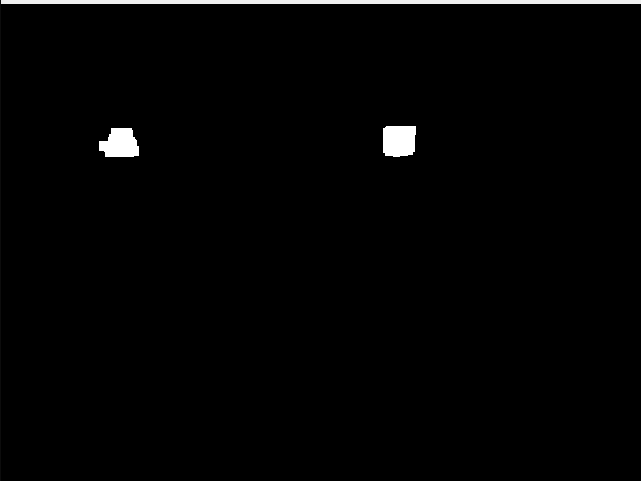
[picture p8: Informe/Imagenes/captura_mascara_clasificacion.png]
         
        \caption{Máscara HSV segmentada, evidenciando las diferentes geometrías.}
        \label{fig:mascara_clasificacion}
    \end{subfigure}
    \caption{Clasificación simultánea de geometrías mediante el cálculo del Extent Rotado.}
    \label{fig:clasificacion_objetos}
\end{figure}
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

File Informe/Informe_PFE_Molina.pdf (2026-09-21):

## Universidad Nacional de Cuyo

### Facultad de Ingeniería

# Proyecto Final de Estudios

### Ingeniería en Mecatrónica

# Integración de Sistema de Visión Artificial y Planificación Dinámica de Trayectorias

### Continuación y evolución del sistema robótico de Agüero y Lezcano

### Alumno: Matías Exequiel Molina Director: Eric Sanchez

### Mendoza, Argentina

2026

## Resumen
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

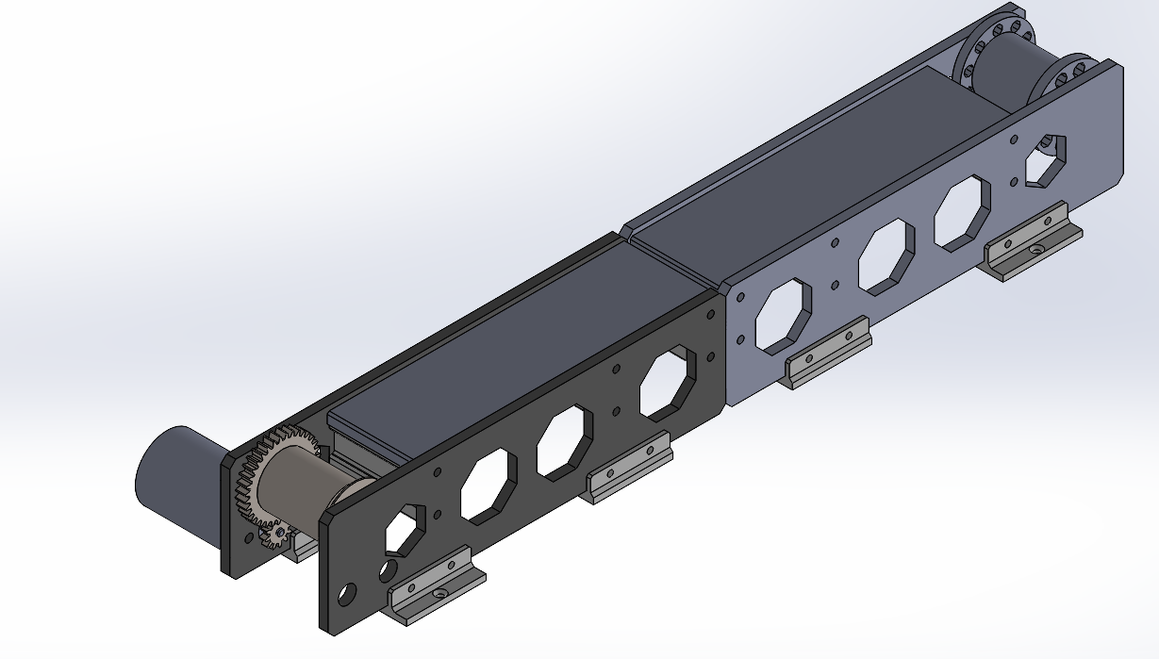
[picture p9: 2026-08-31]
Informe/Imagenes/Cinta.png

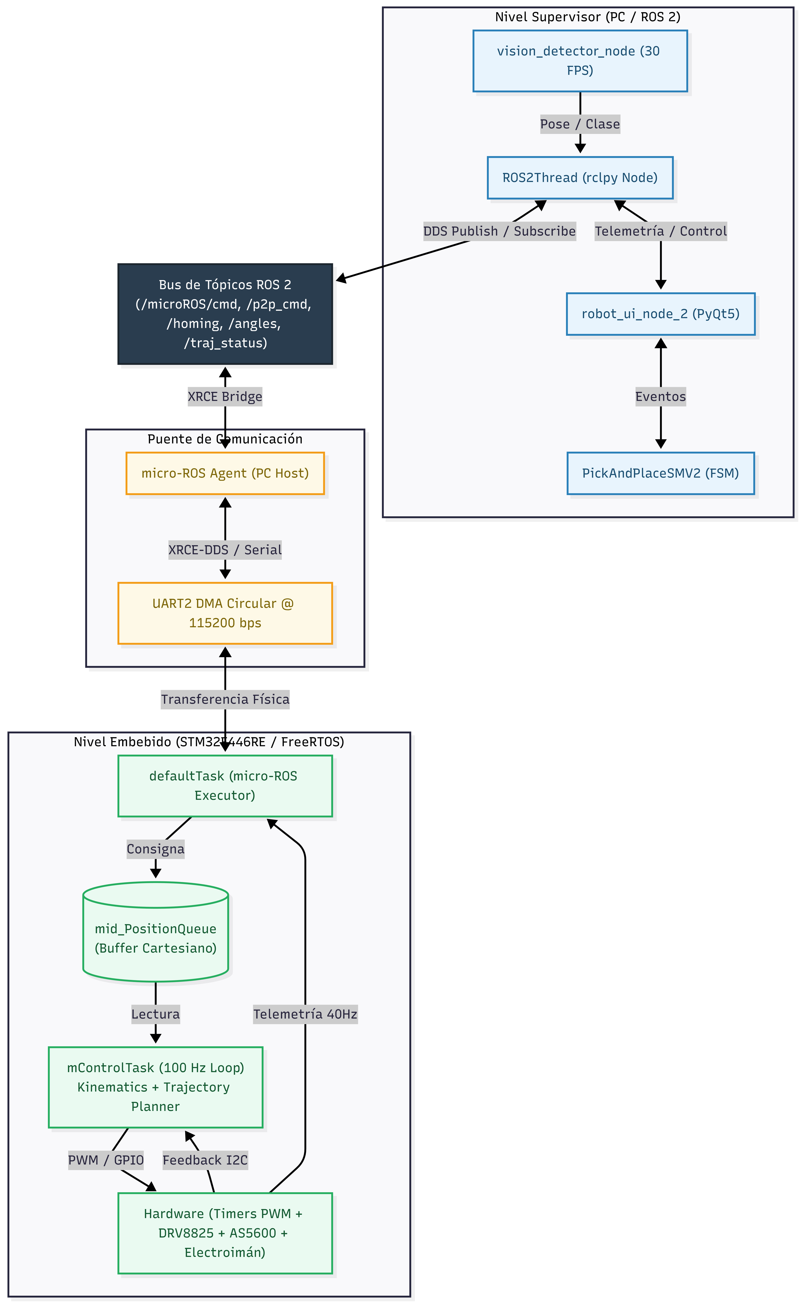
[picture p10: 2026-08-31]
Informe/Imagenes/DiagramaGlobal.png

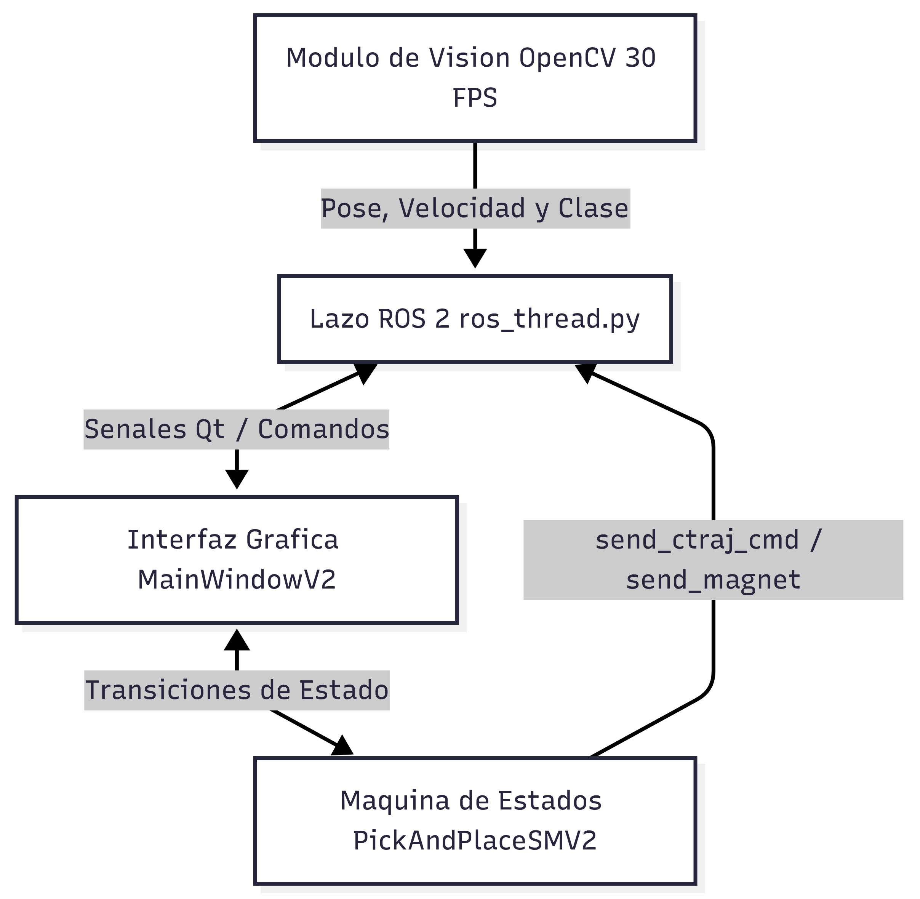
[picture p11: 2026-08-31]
Informe/Imagenes/SupervisorBloquesPrincipales.png

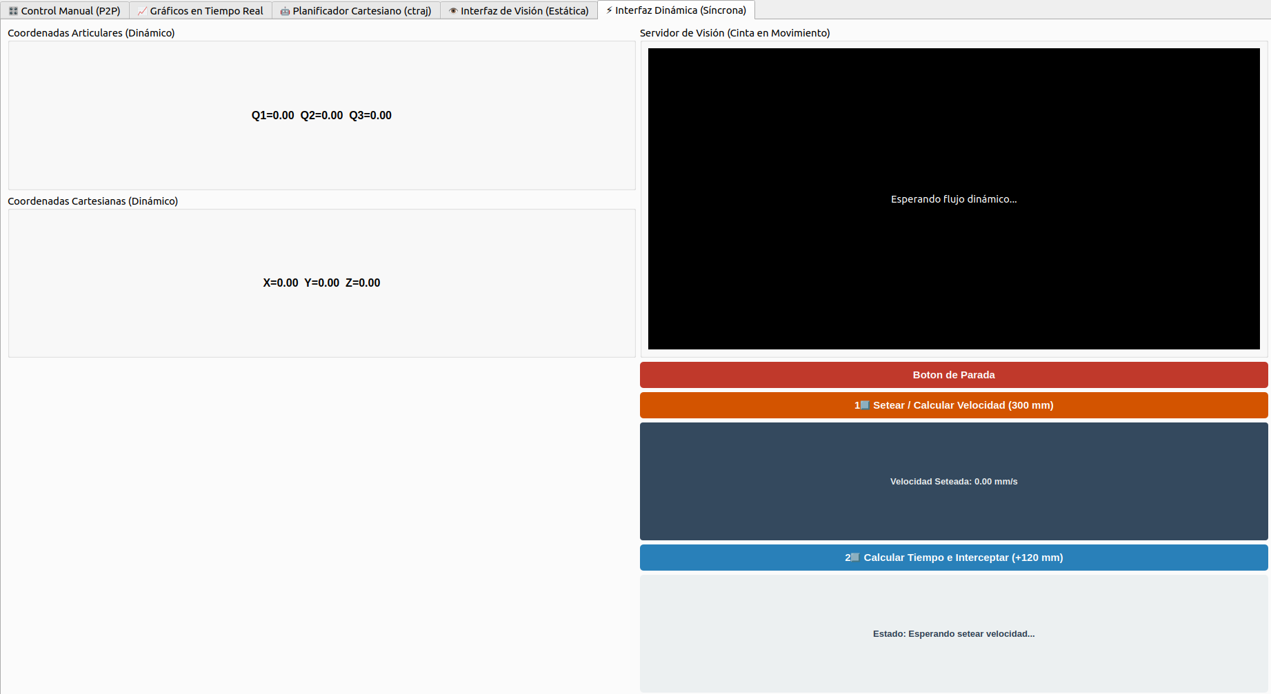
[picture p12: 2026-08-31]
Informe/Imagenes/gui_pestana5.png

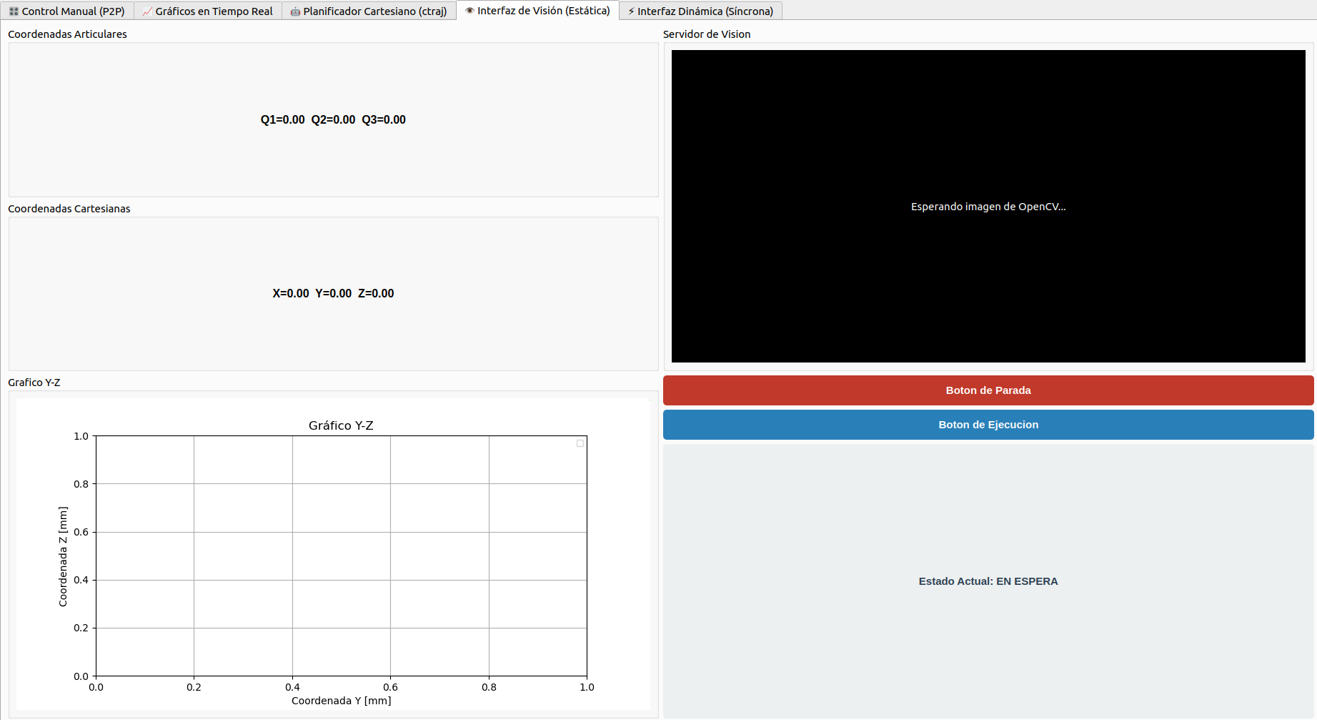
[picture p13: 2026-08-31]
Informe/Imagenes/gui_pestana4.png

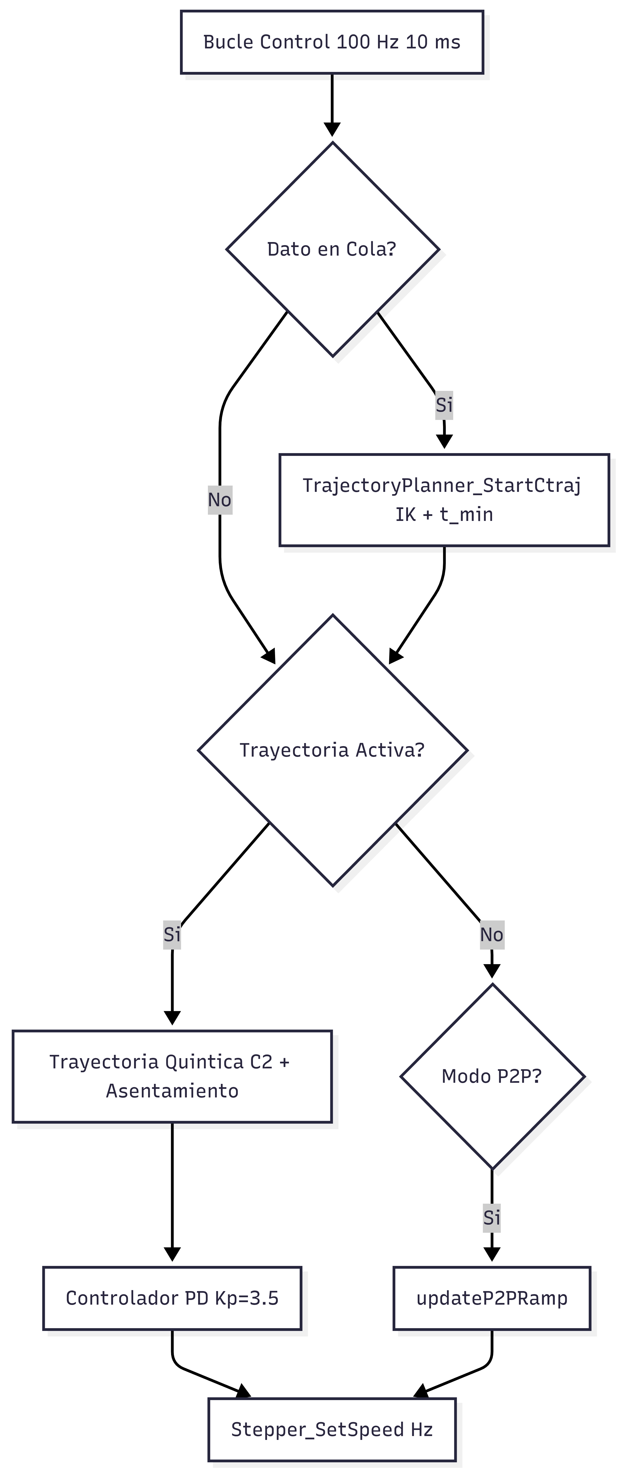
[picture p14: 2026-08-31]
Informe/Imagenes/FirmwareDetalle2.png

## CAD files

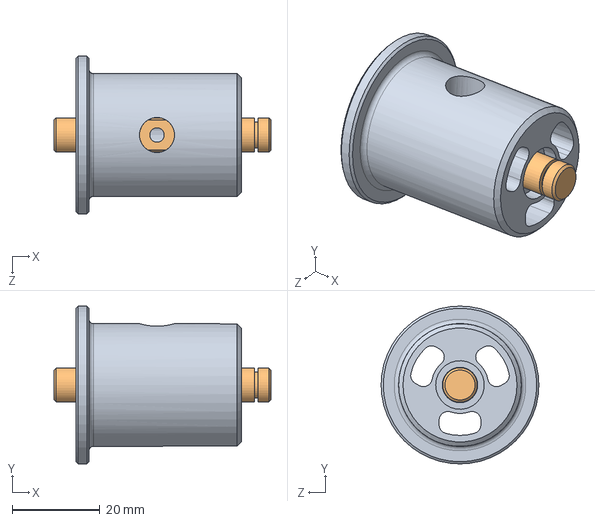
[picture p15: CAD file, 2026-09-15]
Modelo 3D/EnsamblajeEje.SLDASM
49.5 x 36.0 x 36.0 mm
Eje6mm
RodilloConducido

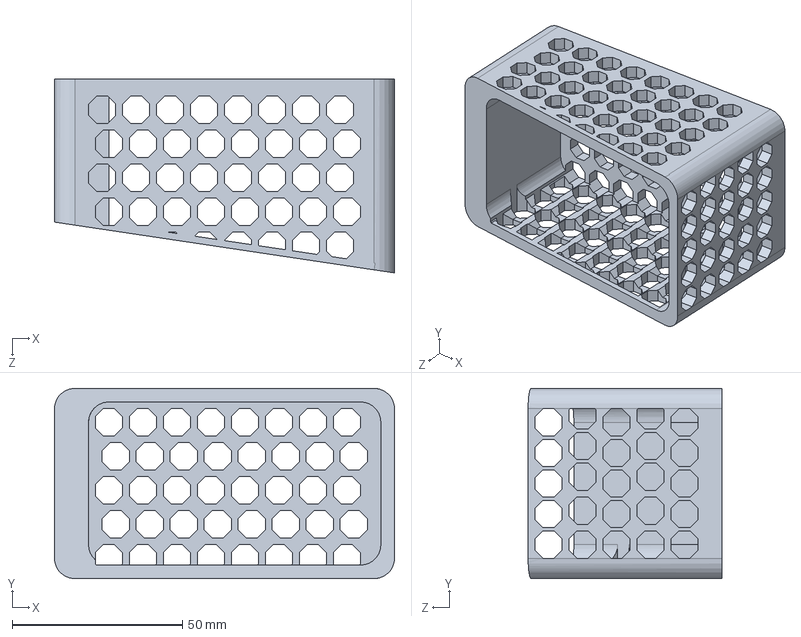
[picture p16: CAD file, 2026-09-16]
Modelo 3D/CuboReceptor.SLDPRT
100.0 x 56.0 x 57.0 mm

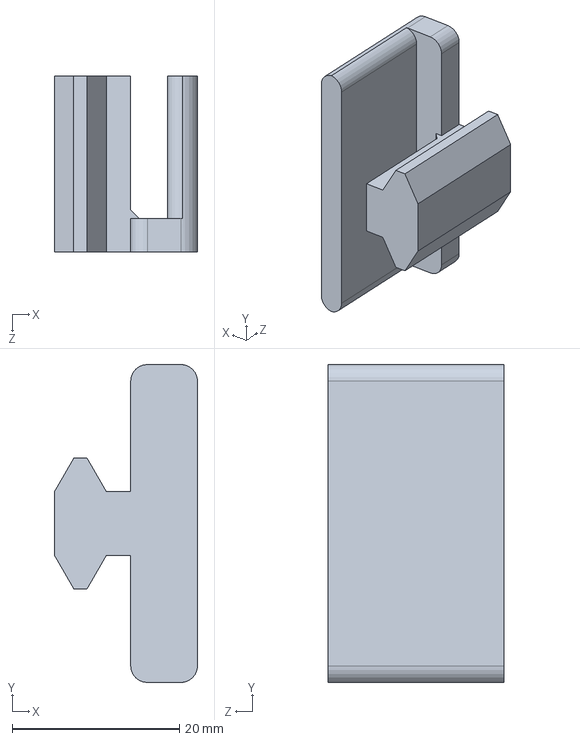
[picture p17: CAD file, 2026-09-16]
Modelo 3D/sujecion.SLDPRT
17.1 x 38.0 x 21.0 mm

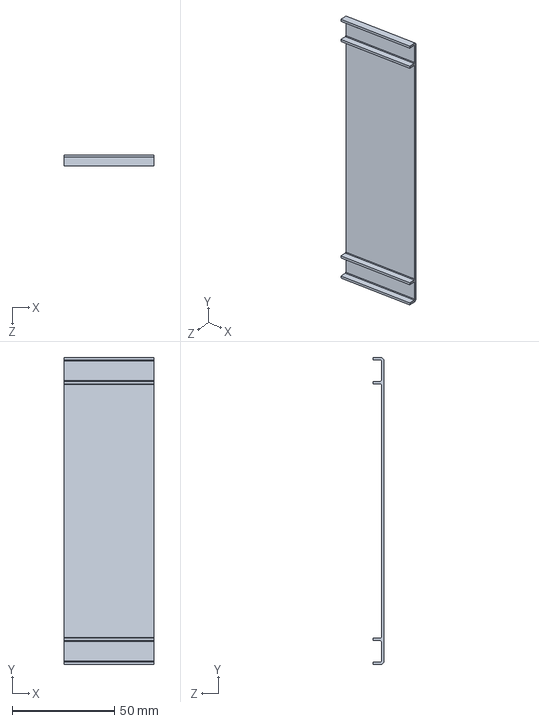
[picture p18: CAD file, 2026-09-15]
Modelo 3D/pisoCinta.SLDPRT
44.0 x 150.4 x 5.20 mm

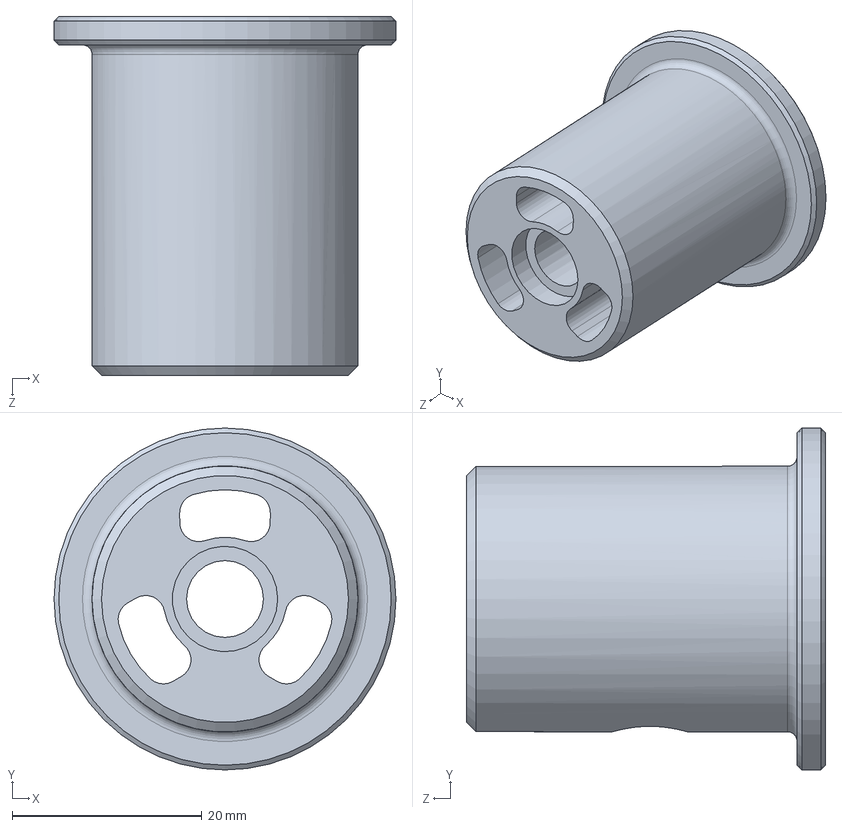
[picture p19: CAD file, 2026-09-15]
Modelo 3D/RodilloConducido.SLDPRT
36.0 x 36.0 x 37.8 mm

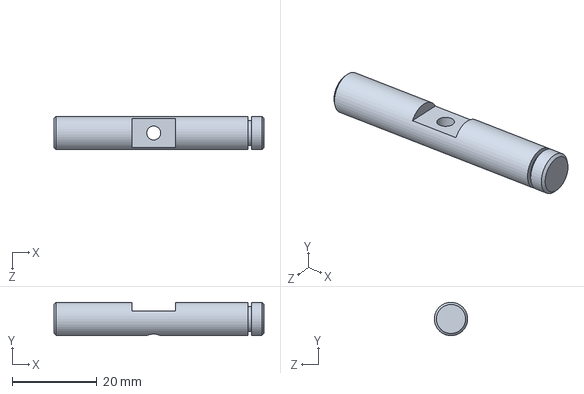
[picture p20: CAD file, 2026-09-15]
Modelo 3D/Eje6mm.SLDPRT
49.5 x 7.85 x 7.86 mm

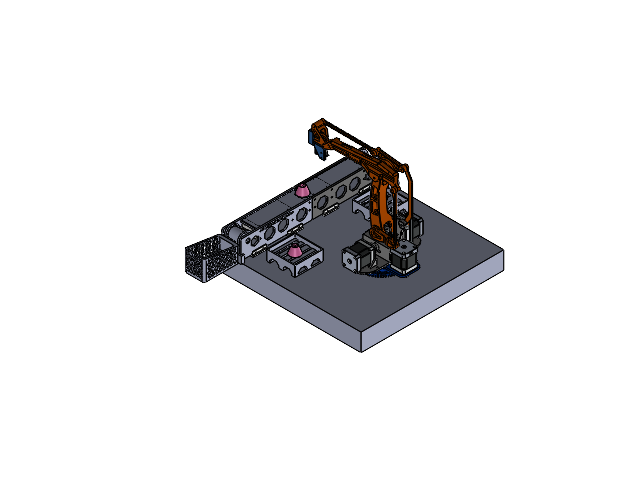
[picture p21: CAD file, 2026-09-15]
Modelo 3D/MaquetaFinal.SLDASM
BaseMaqueta
Lateral21 v2
LateralV2
Separador x 4
Separador2
Buje x 2
Buje2 x 2
MotorDC
Base2 x 6
BaseCagujero x 2
pisoCinta x 2
ejeMotriz2 x 2
ejeMotriz1 x 2
TamborConducidoV3
TapaTamborConducido
EjeMotrizImpreso
tapaTamborMotrizImpreso
spur gear_am
SimetríaLateral21 v2
SimetríaLateralV2
Robot_Base_Low_Gear
Base_Arm2
motorPaPNema17 x 3
Robot_Base_Low
gearMotor1
soporteAS5600v2
tapa_ejes
iman
AS5600
002_mainarm
gear1
gearMotor x 2
006_horarm
007_trialink
005_link 135angled
003 VArm
004_link 135
soporte2Electroiman
Electroiman
009_trialinkfront
008_link 147
ConoObjetivo x 2
PalletCono
PalletCubo
CuboObjetivo
TapaTraseraDelantera x 2
CuboReceptor
sujecion

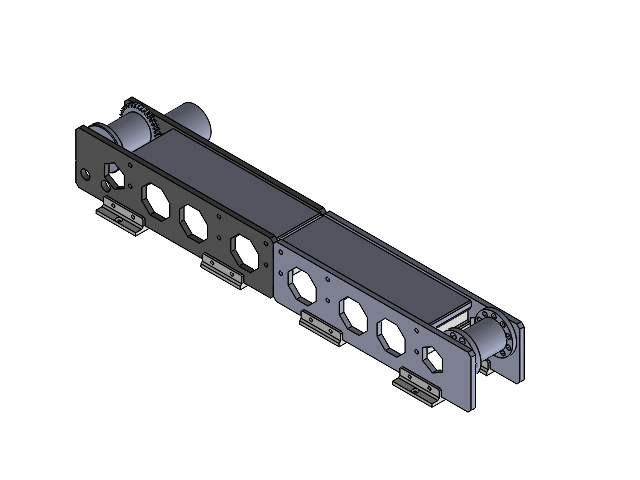
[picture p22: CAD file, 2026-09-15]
Modelo 3D/EnsamblajeCintaV2.SLDASM
Lateral21 v2
LateralV2
Separador x 4
Separador2
Buje x 2
Buje2 x 2
MotorDC
Base2 x 6
BaseCagujero x 2
pisoCinta x 2
ejeMotriz2 x 2
ejeMotriz1 x 2
TamborConducidoV3
TapaTamborConducido
EjeMotrizImpreso
tapaTamborMotrizImpreso
spur gear_am
SimetríaLateral21 v2
SimetríaLateralV2

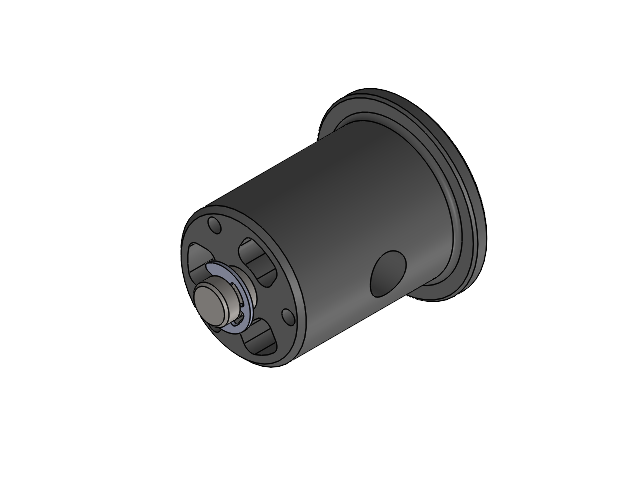
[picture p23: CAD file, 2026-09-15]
Modelo 3D/EnsamblajeEjeMotriz.SLDASM
Eje6mm
RodilloMotriz
arandela_de_retencion_din6799_6

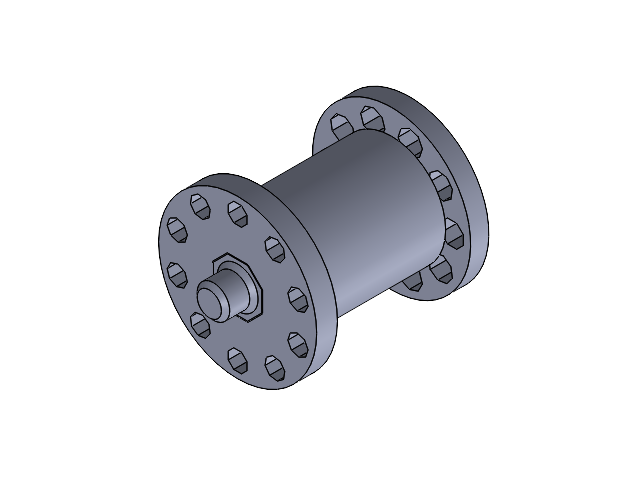
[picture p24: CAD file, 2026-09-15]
Modelo 3D/EjeConducido.SLDASM
ejeMotriz2
ejeMotriz1
TamborConducidoV3
TapaTamborConducido

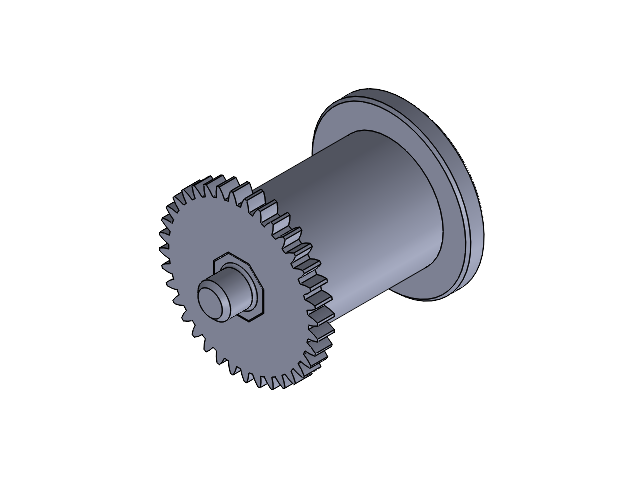
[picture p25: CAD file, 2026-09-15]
Modelo 3D/EjeMotriz.SLDASM
EjeMotrizImpreso
ejeMotriz2
ejeMotriz1
tapaTamborMotrizImpreso

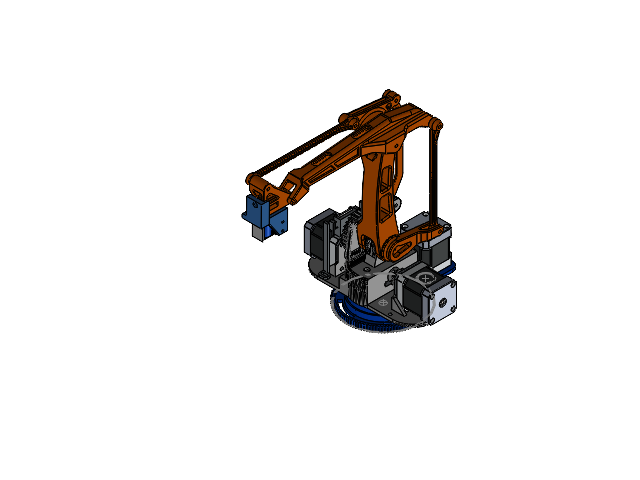
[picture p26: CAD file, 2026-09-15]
Modelo 3D/RobotEEZYArmBotMk2.SLDASM
Robot_Base_Low_Gear
Base_Arm2
motorPaPNema17 x 3
Robot_Base_Low
gearMotor1
soporteAS5600v2
tapa_ejes
iman
AS5600
002_mainarm
gear1
gearMotor x 2
006_horarm
007_trialink
005_link 135angled
003 VArm
004_link 135
soporte2Electroiman
Electroiman
009_trialinkfront
008_link 147

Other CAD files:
Modelo 3D/002_mainarm.SLDPRT
Modelo 3D/sensor_iman.SLDASM
Modelo 3D/Base_with_motors.SLDASM
Modelo 3D/soporteConElectroiman2.SLDASM
Modelo 3D/tapa_ejes.SLDPRT
Modelo 3D/008_link 147.SLDPRT
Modelo 3D/003 VArm.SLDPRT
Modelo 3D/004_link 135.SLDPRT
Modelo 3D/005_link 135angled.SLDPRT
Modelo 3D/006_horarm.SLDPRT
Modelo 3D/007_trialink.SLDPRT
Modelo 3D/009_trialinkfront.SLDPRT
Modelo 3D/AS5600.SLDPRT
Modelo 3D/Base2.SLDPRT
Modelo 3D/BaseCagujero.SLDPRT
Modelo 3D/BaseMaqueta.SLDPRT
Modelo 3D/Base_Arm2.SLDPRT
Modelo 3D/Buje.SLDPRT
Modelo 3D/Buje2.SLDPRT
Modelo 3D/ConoObjetivo.SLDPRT
Modelo 3D/CuboObjetivo.SLDPRT
Modelo 3D/EjeMotrizImpreso.SLDPRT
Modelo 3D/Electroiman.SLDPRT
Modelo 3D/Lateral21 v2.SLDPRT
Modelo 3D/LateralV2.SLDPRT
Modelo 3D/MotorDC.SLDPRT
Modelo 3D/PalletCono.SLDPRT
Modelo 3D/PalletCubo.SLDPRT
Modelo 3D/Robot_Base_Low.SLDPRT
Modelo 3D/Robot_Base_Low_Gear.SLDPRT
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

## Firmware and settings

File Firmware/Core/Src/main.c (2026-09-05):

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
/* Includes ------------------------------------------------------------------*/
#include "main.h"
#include "cmsis_os.h"

/* USER CODE BEGIN Includes */
#include "motors.h"
#include "as5600_tca9548.h"
#include "electromagnet.h"
#include "microros_callbacks.h"
#include "tasks.h"
#include "kinematics.h"
#include "trajectory_planner.h"
/* USER CODE END Includes */

I2C_HandleTypeDef hi2c1;

TIM_HandleTypeDef htim2;
TIM_HandleTypeDef htim3;
TIM_HandleTypeDef htim7;
TIM_HandleTypeDef htim13;

UART_HandleTypeDef huart2;
UART_HandleTypeDef huart3;
DMA_HandleTypeDef hdma_usart2_rx;
DMA_HandleTypeDef hdma_usart2_tx;

/* Definitions for defaultTask */
osThreadId_t defaultTaskHandle;
const osThreadAttr_t defaultTask_attributes = {
  .name = "defaultTask",
  .stack_size = 2048 * 4, // 8 KB para micro-ROS
  .priority = (osPriority_t) osPriorityNormal,
};

/* Definitions for mControlTask */
osThreadId_t mControlTaskHandle;
const osThreadAttr_t mControlTask_attributes = {
  .name = "mControlTask",
  .stack_size = 1000 * 4,
  .priority = (osPriority_t) osPriorityHigh,
};

/* USER CODE BEGIN PV */
/**
 * @brief Cola de mensajes para transferir consignas cartesianas (X, Y, Z, T) entre tareas.
 * @details Desacopla la recepción asíncrona en defaultTask del lazo determinista a 100 Hz en mControlTask[cite: 22].
 */
osMessageQueueId_t mid_PositionQueue;
/* USER CODE END PV */

void SystemClock_Config(void);
static void MX_GPIO_Init(void);
static void MX_DMA_Init(void);
static void MX_USART2_UART_Init(void);
static void MX_USART3_UART_Init(void);
static void MX_TIM2_Init(void);
static void MX_TIM3_Init(void);
static void MX_TIM13_Init(void);
static void MX_I2C1_Init(void);
static void MX_TIM7_Init(void);

/* USER CODE BEGIN PFP */
/**
 * @brief Rutina de interrupción de temporizador para verificar la finalización de rampas P2P.
 * @param[in,out] m Puntero al descriptor del motor asociado al temporizador interviniente.
 */
static void Handle_Motor_Timer_Interrupt(Motor *m);
/* USER CODE END PFP */

/**
  * @brief  Punto de entrada principal del microcontrolador.
  * @retval int Código de retorno (nunca alcanzado tras el inicio del planificador de RTOS).
  */
int main(void)
{
  /* MCU Configuration--------------------------------------------------------*/

  /* Reset de todos los periféricos, inicialización de memoria Flash y SysTick */
  HAL_Init();

  /* Configuración del árbol de reloj del sistema (180 MHz) */
  SystemClock_Config();

  /* Inicialización de controladores y periféricos mapeados por hardware */
  MX_GPIO_Init();
  MX_DMA_Init();
  MX_USART2_UART_Init();
  MX_USART3_UART_Init();
  MX_TIM2_Init();
  MX_TIM3_Init();
  MX_TIM13_Init();
  MX_I2C1_Init();
  MX_TIM7_Init();

  /* USER CODE BEGIN 2 */
  /* Inicialización del estado inicial de los sensores magnéticos absolutos (Lectura bloqueante) */
  motor1.currentAngle = readAngle_AS5600(1);
  motor2.currentAngle = readAngle_AS5600(2);
  motor3.currentAngle = readAngle_AS5600(3);
  electromagnetOn(false);

  /* Inicio del temporizador TIM7 para disparar la máquina de adquisición no bloqueante de I2C */
  HAL_TIM_Base_Start_IT(&htim7);

  /* Detención automática de los contadores PWM durante pausas de depuración por hardware */
  __HAL_DBGMCU_FREEZE_TIM13();
  __HAL_DBGMCU_FREEZE_TIM2();
  __HAL_DBGMCU_FREEZE_TIM3();

  printf("System ready.\r\n");
  printf("Angle1 = %.2f ---- Angle2 = %.2f ---- Angle3 = %.2f\r\n",
          motor1.currentAngle, motor2.currentAngle, motor3.currentAngle);
  /* USER CODE END 2 */

  /* Inicialización del kernel de CMSIS-RTOS V2 */
  osKernelInitialize();

  /* USER CODE BEGIN RTOS_MUTEX */
  /* Mutexes del sistema (reservado) */
  /* USER CODE END RTOS_MUTEX */

  /* USER CODE BEGIN RTOS_SEMAPHORES */
  /* Semáforos binarios y contadores (reservado) */
  /* USER CODE END RTOS_SEMAPHORES */

  /* USER CODE BEGIN RTOS_TIMERS */
  /* Temporizadores software de FreeRTOS (reservado) */
  /* USER CODE END RTOS_TIMERS */

  /* USER CODE BEGIN RTOS_QUEUES */
  /* Instanciación de la cola para comandos cartesianos de trayectoria */
  mid_PositionQueue = osMessageQueueNew(4U, sizeof(CARTESIAN_CMD_t), NULL);
  if (mid_PositionQueue == NULL) {
    printf("Error: Could not create mid_PositionQueue.\r\n");
  }
  /* USER CODE END RTOS_QUEUES */

  /* Creación de tareas concurrentes */
  /* Tarea de comunicación micro-ROS (prioridad normal) */
  defaultTaskHandle = osThreadNew(StartDefaultTask, NULL, &defaultTask_attributes);

  /* Tarea de control cinemático determinista a 100 Hz (alta prioridad) */
  mControlTaskHandle = osThreadNew(StartMotorControlTask, NULL, &mControlTask_attributes);

  /* USER CODE BEGIN RTOS_THREADS */
  /* Hilos de usuario adicionales (reservado) */
  /* USER CODE END RTOS_THREADS */

  /* USER CODE BEGIN RTOS_EVENTS */
  /* Banderas de eventos (reservado) */
  /* USER CODE END RTOS_EVENTS */

  /* Arranque del scheduler de FreeRTOS */
  osKernelStart();

  /* Bucle infinito de trampa por si el kernel cede el control */
  /* USER CODE BEGIN WHILE */
  while (1)
  {
    /* USER CODE END WHILE */

    /* USER CODE BEGIN 3 */
  }
  /* USER CODE END 3 */
}

/**
  * @brief Configura el árbol de reloj del sistema (System Clock Tree).
  * @details Fuente HSI (16 MHz) -> PLL (M=8, N=180, P=2) -> SYSCLK a 180 MHz[cite: 22].
  *          Buses periféricos: AHB = 180 MHz, APB1 = 45 MHz (Timers a 90 MHz), APB2 = 90 MHz[cite: 22].
  * @retval None
  */
void SystemClock_Config(void)
{
  RCC_OscInitTypeDef RCC_OscInitStruct = {0};
  RCC_ClkInitTypeDef RCC_ClkInitStruct = {0};

  /** Configuración del regulador interno de voltaje a máxima frecuencia (Scale 1) */
  __HAL_RCC_PWR_CLK_ENABLE();
  __HAL_PWR_VOLTAGESCALING_CONFIG(PWR_REGULATOR_VOLTAGE_SCALE1);

  /** Configuración del oscilador interno HSI y multiplicación por PLL */
  RCC_OscInitStruct.OscillatorType = RCC_OSCILLATORTYPE_HSI;
  RCC_OscInitStruct.HSIState = RCC_HSI_ON;
  RCC_OscInitStruct.HSICalibrationValue = RCC_HSICALIBRATION_DEFAULT;
  RCC_OscInitStruct.PLL.PLLState = RCC_PLL_ON;
  RCC_OscInitStruct.PLL.PLLSource = RCC_PLLSOURCE_HSI;
  RCC_OscInitStruct.PLL.PLLM = 8;
  RCC_OscInitStruct.PLL.PLLN = 180;
  RCC_OscInitStruct.PLL.PLLP = RCC_PLLP_DIV2;
  RCC_OscInitStruct.PLL.PLLQ = 2;
  RCC_OscInitStruct.PLL.PLLR = 2;
  if (HAL_RCC_OscConfig(&RCC_OscInitStruct) != HAL_OK)
  {
    Error_Handler();
  }

  /** Inicialización de los relojes de buses CPU, AHB y APB */
  RCC_ClkInitStruct.ClockType = RCC_CLOCKTYPE_HCLK|RCC_CLOCKTYPE_SYSCLK
                              |RCC_CLOCKTYPE_PCLK1|RCC_CLOCKTYPE_PCLK2;
  RCC_ClkInitStruct.SYSCLKSource = RCC_SYSCLKSOURCE_PLLCLK;
  RCC_ClkInitStruct.AHBCLKDivider = RCC_SYSCLK_DIV1;
  RCC_ClkInitStruct.APB1CLKDivider = RCC_HCLK_DIV4;
  RCC_ClkInitStruct.APB2CLKDivider = RCC_HCLK_DIV2;

  if (HAL_RCC_ClockConfig(&RCC_ClkInitStruct, FLASH_LATENCY_5) != HAL_OK)
  {
    Error_Handler();
  }
}

/**
  * @brief Inicializa el periférico I2C1 para el bus de adquisición de encoders (Fast Mode 400 kHz).
  * @param None
  * @retval None
  */
static void MX_I2C1_Init(void)
{
  hi2c1.Instance = I2C1;
  hi2c1.Init.ClockSpeed = 400000;
  hi2c1.Init.DutyCycle = I2C_DUTYCYCLE_2;
  hi2c1.Init.OwnAddress1 = 0;
  hi2c1.Init.AddressingMode = I2C_ADDRESSINGMODE_7BIT;
  hi2c1.Init.DualAddressMode = I2C_DUALADDRESS_DISABLE;
  hi2c1.Init.OwnAddress2 = 0;
  hi2c1.Init.GeneralCallMode = I2C_GENERALCALL_DISABLE;
  hi2c1.Init.NoStretchMode = I2C_NOSTRETCH_DISABLE;
  if (HAL_I2C_Init(&hi2c1) != HAL_OK)
  {
    Error_Handler();
  }
}

/**
  * @brief Inicializa el temporizador de 32 bits TIM2 para el canal PWM del Motor 2 (Hombro).
  * @param None
  * @retval None
  */
static void MX_TIM2_Init(void)
{
  TIM_ClockConfigTypeDef sClockSourceConfig = {0};
  TIM_MasterConfigTypeDef sMasterConfig = {0};
  TIM_OC_InitTypeDef sConfigOC = {0};

  htim2.Instance = TIM2;
  htim2.Init.Prescaler = 83;
  htim2.Init.CounterMode = TIM_COUNTERMODE_UP;
  htim2.Init.Period = 999;
  htim2.Init.ClockDivision = TIM_CLOCKDIVISION_DIV1;
  htim2.Init.AutoReloadPreload = TIM_AUTORELOAD_PRELOAD_ENABLE;
  if (HAL_TIM_Base_Init(&htim2) != HAL_OK)
  {
    Error_Handler();
  }
  sClockSourceConfig.ClockSource = TIM_CLOCKSOURCE_INTERNAL;
  if (HAL_TIM_ConfigClockSource(&htim2, &sClockSourceConfig) != HAL_OK)
  {
    Error_Handler();
  }
  if (HAL_TIM_PWM_Init(&htim2) != HAL_OK)
  {
    Error_Handler();
  }
  sMasterConfig.MasterOutputTrigger = TIM_TRGO_UPDATE;
  sMasterConfig.MasterSlaveMode = TIM_MASTERSLAVEMODE_DISABLE;
  if (HAL_TIMEx_MasterConfigSynchronization(&htim2, &sMasterConfig) != HAL_OK)
  {
    Error_Handler();
  }
  sConfigOC.OCMode = TIM_OCMODE_PWM1;
  sConfigOC.Pulse = 0;
  sConfigOC.OCPolarity = TIM_OCPOLARITY_HIGH;
  sConfigOC.OCFastMode = TIM_OCFAST_DISABLE;
  if (HAL_TIM_PWM_ConfigChannel(&htim2, &sConfigOC, TIM_CHANNEL_2) != HAL_OK)
  {
    Error_Handler();
  }
  HAL_TIM_MspPostInit(&htim2);
}

/**
  * @brief Inicializa el temporizador de 16 bits TIM3 para el canal PWM del Motor 3 (Muñeca).
  * @param None
  * @retval None
  */
static void MX_TIM3_Init(void)
{
  TIM_ClockConfigTypeDef sClockSourceConfig = {0};
  TIM_MasterConfigTypeDef sMasterConfig = {0};
  TIM_OC_InitTypeDef sConfigOC = {0};

  htim3.Instance = TIM3;
  htim3.Init.Prescaler = 83;
  htim3.Init.CounterMode = TIM_COUNTERMODE_UP;
  htim3.Init.Period = 999;
  htim3.Init.ClockDivision = TIM_CLOCKDIVISION_DIV1;
  htim3.Init.AutoReloadPreload = TIM_AUTORELOAD_PRELOAD_ENABLE;
  if (HAL_TIM_Base_Init(&htim3) != HAL_OK)
  {
    Error_Handler();
  }
  sClockSourceConfig.ClockSource = TIM_CLOCKSOURCE_INTERNAL;
  if (HAL_TIM_ConfigClockSource(&htim3, &sClockSourceConfig) != HAL_OK)
  {
    Error_Handler();
  }
  if (HAL_TIM_PWM_Init(&htim3) != HAL_OK)
  {
    Error_Handler();
  }
  sMasterConfig.MasterOutputTrigger = TIM_TRGO_UPDATE;
  sMasterConfig.MasterSlaveMode = TIM_MASTERSLAVEMODE_DISABLE;
  if (HAL_TIMEx_MasterConfigSynchronization(&htim3, &sMasterConfig) != HAL_OK)
  {
    Error_Handler();
  }
  sConfigOC.OCMode = TIM_OCMODE_PWM1;
  sConfigOC.Pulse = 0;
  sConfigOC.OCPolarity = TIM_OCPOLARITY_HIGH;
  sConfigOC.OCFastMode = TIM_OCFAST_DISABLE;
  if (HAL_TIM_PWM_ConfigChannel(&htim3, &sConfigOC, TIM_CHANNEL_2) != HAL_OK)
  {
    Error_Handler();
  }
  HAL_TIM_MspPostInit(&htim3);
}

/**
  * @brief Inicializa el temporizador básico TIM7 como base de tiempo de adquisición sensorial.
  * @param None
  * @retval None
  */
static void MX_TIM7_Init(void)
{
  TIM_MasterConfigTypeDef sMasterConfig = {0};

  htim7.Instance = TIM7;
  htim7.Init.Prescaler = 83;
  htim7.Init.CounterMode = TIM_COUNTERMODE_UP;
  htim7.Init.Period = 9999;
  htim7.Init.AutoReloadPreload = TIM_AUTORELOAD_PRELOAD_ENABLE;
  if (HAL_TIM_Base_Init(&htim7) != HAL_OK)
  {
    Error_Handler();
  }
  sMasterConfig.MasterOutputTrigger = TIM_TRGO_UPDATE;
  sMasterConfig.MasterSlaveMode = TIM_MASTERSLAVEMODE_DISABLE;
  if (HAL_TIMEx_MasterConfigSynchronization(&htim7, &sMasterConfig) != HAL_OK)
  {
    Error_Handler();
  }
}

/**
  * @brief Inicializa el temporizador de 16 bits TIM13 para el canal PWM del Motor 1 (Cintura).
  * @param None
  * @retval None
  */
static void MX_TIM13_Init(void)
{
  TIM_OC_InitTypeDef sConfigOC = {0};

  htim13.Instance = TIM13;
  htim13.Init.Prescaler = 83;
  htim13.Init.CounterMode = TIM_COUNTERMODE_UP;
  htim13.Init.Period = 999;
  htim13.Init.ClockDivision = TIM_CLOCKDIVISION_DIV1;
  htim13.Init.AutoReloadPreload = TIM_AUTORELOAD_PRELOAD_ENABLE;
  if (HAL_TIM_Base_Init(&htim13) != HAL_OK)
  {
    Error_Handler();
  }
  if (HAL_TIM_PWM_Init(&htim13) != HAL_OK)
  {
    Error_Handler();
  }
  sConfigOC.OCMode = TIM_OCMODE_PWM1;
  sConfigOC.Pulse = 0;
  sConfigOC.OCPolarity = TIM_OCPOLARITY_HIGH;
  sConfigOC.OCFastMode = TIM_OCFAST_DISABLE;
  if (HAL_TIM_PWM_ConfigChannel(&htim13, &sConfigOC, TIM_CHANNEL_1) != HAL_OK)
  {
    Error_Handler();
  }
  HAL_TIM_MspPostInit(&htim13);
}

/**
  * @brief Inicializa el puerto USART2 a 115200 bps para el canal de transporte serie de micro-ROS.
  * @param None
  * @retval None
  */
static void MX_USART2_UART_Init(void)
{
  huart2.Instance = USART2;
  huart2.Init.BaudRate = 115200;
  huart2.Init.WordLength = UART_WORDLENGTH_8B;
  huart2.Init.StopBits = UART_STOPBITS_1;
  huart2.Init.Parity = UART_PARITY_NONE;
  huart2.Init.Mode = UART_MODE_TX_RX;
  huart2.Init.HwFlowCtl = UART_HWCONTROL_NONE;
  huart2.Init.OverSampling = UART_OVERSAMPLING_16;
  if (HAL_UART_Init(&huart2) != HAL_OK)
  {
    Error_Handler();
  }
}

/**
  * @brief Inicializa el puerto USART3 a 115200 bps hacia el ST-LINK VCP para depuración (printf).
  * @param None
  * @retval None
  */
static void MX_USART3_UART_Init(void)
{
  huart3.Instance = USART3;
  huart3.Init.BaudRate = 115200;
  huart3.Init.WordLength = UART_WORDLENGTH_8B;
  huart3.Init.StopBits = UART_STOPBITS_1;
  huart3.Init.Parity = UART_PARITY_NONE;
  huart3.Init.Mode = UART_MODE_TX_RX;
  huart3.Init.HwFlowCtl = UART_HWCONTROL_NONE;
  huart3.Init.OverSampling = UART_OVERSAMPLING_16;
  if (HAL_UART_Init(&huart3) != HAL_OK)
  {
    Error_Handler();
  }
}

/**
  * @brief Inicializa el controlador de acceso directo a memoria (DMA) para USART2.
  */
static void MX_DMA_Init(void)
{
  __HAL_RCC_DMA1_CLK_ENABLE();

  /* Configuración de interrupciones para RX (Stream 5) y TX (Stream 6) */
  HAL_NVIC_SetPriority(DMA1_Stream5_IRQn, 5, 0);
  HAL_NVIC_EnableIRQ(DMA1_Stream5_IRQn);
  HAL_NVIC_SetPriority(DMA1_Stream6_IRQn, 5, 0);
  HAL_NVIC_EnableIRQ(DMA1_Stream6_IRQn);
}

/**
  * @brief Configura los puertos y pines GPIO de propósito general (señales DIR, MOSFET y pulsador).
  * @param None
  * @retval None
  */
static void MX_GPIO_Init(void)
{
  GPIO_InitTypeDef GPIO_InitStruct = {0};

  __HAL_RCC_GPIOC_CLK_ENABLE();
  __HAL_RCC_GPIOH_CLK_ENABLE();
  __HAL_RCC_GPIOA_CLK_ENABLE();
  __HAL_RCC_GPIOB_CLK_ENABLE();

  HAL_GPIO_WritePin(GPIOC, GPIO_PIN_3|GPIO_PIN_7, GPIO_PIN_RESET);
  HAL_GPIO_WritePin(GPIOA, GPIO_PIN_5|GPIO_PIN_8, GPIO_PIN_RESET);
  HAL_GPIO_WritePin(GPIOB, GPIO_PIN_10, GPIO_PIN_RESET);

  /* Pulsador de usuario azul (B1) */
  GPIO_InitStruct.Pin = B1_Pin;
  GPIO_InitStruct.Mode = GPIO_MODE_IT_FALLING;
  GPIO_InitStruct.Pull = GPIO_NOPULL;
  HAL_GPIO_Init(B1_GPIO_Port, &GPIO_InitStruct);

  /* Salidas de potencia del solenoide (PC3) y LED testigo (PC7) */
  GPIO_InitStruct.Pin = GPIO_PIN_3|GPIO_PIN_7;
  GPIO_InitStruct.Mode = GPIO_MODE_OUTPUT_PP;
  GPIO_InitStruct.Pull = GPIO_NOPULL;
  GPIO_InitStruct.Speed = GPIO_SPEED_FREQ_LOW;
  HAL_GPIO_Init(GPIOC, &GPIO_InitStruct);

  /* Salidas de dirección para drivers DRV8825: DIR1 (PA5) y DIR3 (PA8) */
  GPIO_InitStruct.Pin = GPIO_PIN_5|GPIO_PIN_8;
  GPIO_InitStruct.Mode = GPIO_MODE_OUTPUT_PP;
  GPIO_InitStruct.Pull = GPIO_NOPULL;
  GPIO_InitStruct.Speed = GPIO_SPEED_FREQ_LOW;
  HAL_GPIO_Init(GPIOA, &GPIO_InitStruct);

  /* Salida de dirección: DIR2 (PB10) */
  GPIO_InitStruct.Pin = GPIO_PIN_10;
  GPIO_InitStruct.Mode = GPIO_MODE_OUTPUT_PP;
  GPIO_InitStruct.Pull = GPIO_NOPULL;
  GPIO_InitStruct.Speed = GPIO_SPEED_FREQ_LOW;
  HAL_GPIO_Init(GPIOB, &GPIO_InitStruct);

  /* Entrada auxiliar PB6 */
  GPIO_InitStruct.Pin = GPIO_PIN_6;
  GPIO_InitStruct.Mode = GPIO_MODE_INPUT;
  GPIO_InitStruct.Pull = GPIO_NOPULL;
  HAL_GPIO_Init(GPIOB, &GPIO_InitStruct);
}

/* USER CODE BEGIN 4 */
/**
 * @brief Redirección de caracteres para la salida estándar stdout/printf hacia el puerto USART3.
 *
 * @param[in] ch Byte/carácter a transmitir.
 * @return int Carácter transmitido.
 */
int __io_putchar(int ch) {
  HAL_UART_Transmit(&huart3, (uint8_t*) &ch, 1U, HAL_MAX_DELAY);
  return ch;
}

/**
 * @brief Evalúa la condición de finalización de un eje durante movimientos punto a punto (P2P).
 *
 * @details Comprueba si la lectura del encoder magnético ha ingresado en la banda de tolerancia
 * (ANGLE_TOLERANCE) respecto al ángulo meta. Al alcanzar la meta o ante fallo de hardware, detiene
 * las interrupciones del timer, apaga la modulación PWM y commuta el actuador al estado IDLE[cite: 22].
 *
 * @param[in,out] m Puntero al descriptor del motor a inspeccionar[cite: 22].
 */
static void Handle_Motor_Timer_Interrupt(Motor *m) {
  switch (m->state) {
    case HOMING:
    case P2P: {
      bool target_reached = false;

      if (m->dir == GPIO_PIN_SET) {
        if (m->currentAngle >= (m->targetAngle - ANGLE_TOLERANCE)) {
          target_reached = true;
        }
      } else {
        if (m->currentAngle <= (m->targetAngle + ANGLE_TOLERANCE)) {
          target_reached = true;
        }
      }

      if (target_reached) {
        m->state = IDLE;
        HAL_TIM_Base_Stop_IT(m->timer);
        HAL_TIM_PWM_Stop(m->timer, m->timerChannel);
      }
      break;
    }

    case MOTOR_ERROR:
      HAL_TIM_Base_Stop_IT(m->timer);
      HAL_TIM_PWM_Stop(m->timer, m->timerChannel);
      break;

    default:
      break;
  }
}

/**
 * @brief Callback global del HAL al completarse el periodo de cualquiera de los temporizadores activos.
 *
 * @details Distribuye las interrupciones periódicas:
 *  - **TIM13, TIM2, TIM3:** Disparan el chequeo de llegada para los motores 1, 2 y 3 respectivamente[cite: 22].
 *  - **TIM7:** Si el bus se encuentra en reposo (I2C_IDLE), inicia la lectura del siguiente encoder
 *    en un esquema secuencial no bloqueante tipo Round-Robin (1 -> 2 -> 3 -> 1)[cite: 22].
 *  - **TIM1:** Incrementa el contador de tiempo base (uwTick) del HAL de ST[cite: 22].
 *
 * @param[in] htim Puntero al manejador del temporizador que disparó la interrupción[cite: 22].
 */
void HAL_TIM_PeriodElapsedCallback(TIM_HandleTypeDef *htim)
{
  static uint8_t sensor_index = 1;

  if (htim->Instance == TIM13) {
    Handle_Motor_Timer_Interrupt(&motor1);
  }
  else if (htim->Instance == TIM2) {
    Handle_Motor_Timer_Interrupt(&motor2);
  }
  else if (htim->Instance == TIM3) {
    Handle_Motor_Timer_Interrupt(&motor3);
  }
  else if (htim->Instance == TIM7) {
    if (i2c_state == I2C_IDLE) {
      AS5600_StartRead_IT(sensor_index);
      sensor_index++;
      if (sensor_index > 3U) sensor_index = 1U;
    }
  }

  if (htim->Instance == TIM1)
  {
    HAL_IncTick();
  }
}
/* USER CODE END 4 */

/**
  * @brief  Manejador de excepciones críticas de hardware o inicialización fallida.
  * @retval None
  */
void Error_Handler(void)
{
  /* USER CODE BEGIN Error_Handler_Debug */
  __disable_irq();
  while (1)
  {
  }
  /* USER CODE END Error_Handler_Debug */
}

#ifdef  USE_FULL_ASSERT
void assert_failed(uint8_t *file, uint32_t line)
{
}
#endif /* USE_FULL_ASSERT */

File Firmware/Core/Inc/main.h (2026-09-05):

/**
 * @file main.h
 * @brief Cabecera principal del sistema de control embebido y mapeo de hardware.
 * @author Matías Exequiel Molina <ingenieria@uncuyo.edu.ar>
 * @date 2026
 *
 * @details Centraliza las definiciones globales del microcontrolador STM32F446RE,
 * incluyendo el mapeo de pines para el control de potencia (drivers DRV8825 y MOSFET del efector),
 * direcciones físicas sobre el bus I2C a 400 kHz, temporizadores para modulación PWM por hardware,
 * estructuras de datos cartesianas y macros de validación para la pila de cliente micro-ROS (RCLC).
 */

#ifndef __MAIN_H
#define __MAIN_H

#ifdef __cplusplus
extern "C" {
#endif

/* Includes ------------------------------------------------------------------*/
#include "stm32f4xx_hal.h"
#include <stdio.h>
#include <stdbool.h>
#include <rcl/rcl.h>

/* Exported types ------------------------------------------------------------*/

/**
 * @brief Estructura para almacenamiento de coordenadas cartesianas tridimensionales.
 * @note Utilizada para telemetría interna y cálculos de cinemática directa.
 */
typedef struct {
    double x;   /**< Posición en el eje longitudinal X [mm] */
    double y;   /**< Posición en el eje transversal Y [mm] */
    double z;   /**< Posición en el eje vertical Z [mm] */
} CARTESIAN_POS_t;

/* Exported constants --------------------------------------------------------*/

/** @brief Manejador del temporizador TIM2 para generación PWM del Motor 2 (Hombro / Q2). */
extern TIM_HandleTypeDef htim2;

/** @brief Manejador del temporizador TIM3 para generación PWM del Motor 3 (Muñeca / Q3). */
extern TIM_HandleTypeDef htim3;

/** @brief Manejador del temporizador TIM13 para generación PWM del Motor 1 (Cintura / Q1). */
extern TIM_HandleTypeDef htim13;

/* Exported macros -----------------------------------------------------------*/

/**
 * @brief Macro de validación estricta para llamadas al middleware micro-ROS (RCL).
 * @details Evalúa el código de retorno. Si no es RCL_RET_OK, imprime un reporte de diagnóstico
 * por consola con línea y código de error, y aborta la tarea FreeRTOS invocante de forma segura.
 * @param[in] fn Función o expresión RCL a evaluar.
 */
#define RCCHECK(fn) { \
    rcl_ret_t temp_rc = fn; \
    if((temp_rc != RCL_RET_OK)){ \
        printf("Failed status on line %d: %d. Aborting.\n", __LINE__, (int)temp_rc); \
        vTaskDelete(NULL); \
    } \
}

/**
 * @brief Macro de validación no bloqueante para funciones secundarias de micro-ROS.
 * @details Registra la advertencia por consola pero permite que la ejecución continúe sin abortar el hilo.
 * @param[in] fn Función o expresión RCL a evaluar.
 */
#define RCSOFTCHECK(fn) { \
    rcl_ret_t temp_rc = fn; \
    if((temp_rc != RCL_RET_OK)){ \
        printf("Failed status on line %d: %d. Continuing.\n", __LINE__, (int)temp_rc); \
    } \
}

/* Exported functions prototypes ---------------------------------------------*/

/**
 * @brief Inicializa los puertos GPIO asignados a las salidas auxiliares de los temporizadores.
 * @param[in,out] htim Puntero al temporizador hardware configurado.
 */
void HAL_TIM_MspPostInit(TIM_HandleTypeDef *htim);

/**
 * @brief Manejador de fallas críticas de hardware o inicialización de periféricos HAL.
 * @details Bloquea la CPU en un bucle infinito para preservar la integridad del sistema mecánico.
 */
void Error_Handler(void);

/**
 * @brief Redirección de salida de caracteres (printf) hacia el puerto serie UART para depuración.
 * @param[in] ch Carácter a transmitir.
 * @return Carácter transmitido en caso de éxito.
 */
int __io_putchar(int ch);

/* Private defines -----------------------------------------------------------*/

/* --- Señales estándar de la placa NUCLEO-F446RE y depuración SWD --- */
#define B1_Pin                  GPIO_PIN_13
#define B1_GPIO_Port            GPIOC
#define USART_TX_Pin            GPIO_PIN_2
#define USART_TX_GPIO_Port      GPIOA
#define USART_RX_Pin            GPIO_PIN_3
#define USART_RX_GPIO_Port      GPIOA
#define TMS_Pin                 GPIO_PIN_13
#define TMS_GPIO_Port           GPIOA
#define TCK_Pin                 GPIO_PIN_14
#define TCK_GPIO_Port           GPIOA

/* --- Mapeo de salidas de dirección (DIR) para controladores paso a paso DRV8825 --- */
#define DIR1_GPIO               GPIOA           /**< Puerto GPIO de dirección: Motor 1 (Cintura) */
#define DIR1_PIN                GPIO_PIN_5      /**< Pin GPIO de dirección: Motor 1 (Cintura) */

#define DIR2_GPIO               GPIOB           /**< Puerto GPIO de dirección: Motor 2 (Hombro) */
#define DIR2_PIN                GPIO_PIN_10     /**< Pin GPIO de dirección: Motor 2 (Hombro) */

#define DIR3_GPIO               GPIOA           /**< Puerto GPIO de dirección: Motor 3 (Muñeca) */
#define DIR3_PIN                GPIO_PIN_8      /**< Pin GPIO de dirección: Motor 3 (Muñeca) */
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

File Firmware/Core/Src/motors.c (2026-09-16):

/**
 * @file motors.c
 * @brief Accionamiento de bajo nivel de actuadores paso a paso y lazos de control de movimiento.
 * @author Matías Exequiel Molina <matimolina123@gmail.com>
 * @date 2026
 *
 * @details Este módulo gestiona los controladores DRV8825 mediante modulación PWM generada por
 * periféricos temporizadores STM32 (TIM2, TIM3, TIM13) y control digital de dirección por GPIO.
 * Implementa dos leyes de control diferenciadas según el modo operativo:
 *  - **Modo P2P:** Control proporcional y derivativo sobre velocidad real filtrada para posicionamiento articular.
 *  - **Modo TRAJ:** Control con prealimentación de velocidad (Feedforward) y realimentación proporcional (P)
 *    sobre el error de posición articular para seguimiento continuo de perfiles quínticos.
 */

#include "motors.h"
#include "main.h"
#include <math.h>

#ifndef M_PI_F
#define M_PI_F (3.14159265358979323846f)
#endif

#define DEG_TO_RAD_M    (M_PI_F / 180.0f)
#define STEPS_PER_REV   (200 * 8)                 /**< 200 pasos/rev * 8 micropasos = 1600 pulsos/rev */
#define DEG_TO_STEPS    ((float)STEPS_PER_REV / 360.0f) /**< Factor de escala angular a pulsos [pulsos/°] */

/* =========================================================================
 * INSTANCIAS GLOBALES DE DESCRIPTORES DE MOTOR
 * ========================================================================= */

/** @brief Descriptor del Motor 1: Cintura (Eje azimutal) */
Motor motor1 = {
    .id = 1,
    .i = 108.0f / 19.0f,
    .angleHoming = 0.0f,
    .DIR_PORT = DIR1_GPIO,
    .DIR_PIN = DIR1_PIN,
    .timer = &htim13,
    .timerChannel = TIM_CHANNEL_1,
    .state = IDLE,
    .speed = 0.0f,
    .targetSpeed = MAX_V_HZ,
    .minSpeed = MIN_SPEED_HZ,
    .accel = MAX_A_HZ_S,
    .Kp = 4.5f,
    .Kd = 0.10f,
    .Kg = 0.0f,
    .lastAngleForDeriv = 0.0f,
    .filteredVel = 0.0f
};

/** @brief Descriptor del Motor 2: Hombro (Eje principal de elevación) */
Motor motor2 = {
    .id = 2,
    .i = 32.0f / 12.0f,
    .angleHoming = 90.0f,
    .DIR_PORT = DIR2_GPIO,
    .DIR_PIN = DIR2_PIN,
    .timer = &htim2,
    .timerChannel = TIM_CHANNEL_2,
    .state = IDLE,
    .speed = 0.0f,
    .targetSpeed = MAX_V_HZ,
    .minSpeed = MIN_SPEED_HZ,
    .accel = MAX_A_HZ_S,
    .Kp = 5.0f,
    .Kd = 0.18f,
    .Kg = 0.0f,
    .lastAngleForDeriv = 90.0f,
    .filteredVel = 0.0f
};

/** @brief Descriptor del Motor 3: Muñeca (Eje de antebrazo / paralelogramo) */
Motor motor3 = {
    .id = 3,
    .i = 32.0f / 12.0f,
    .angleHoming = 0.0f,
    .DIR_PORT = DIR3_GPIO,
    .DIR_PIN = DIR3_PIN,
    .timer = &htim3,
    .timerChannel = TIM_CHANNEL_2,
    .state = IDLE,
    .speed = 0.0f,
    .targetSpeed = MAX_V_HZ,
    .minSpeed = MIN_SPEED_HZ,
    .accel = MAX_A_HZ_S,
    .Kp = 4.5f,
    .Kd = 0.12f,
    .Kg = 0.0f,
    .lastAngleForDeriv = 0.0f,
    .filteredVel = 0.0f
};

/** @brief Arreglo de punteros para acceso indexado a los actuadores */
Motor* motors[] = { &motor1, &motor2, &motor3 };

/**
 * @brief Configura directamente el registro Auto-Reload (ARR) del temporizador para ajustar la frecuencia PWM.
 *
 * @details Calcula el periodo ARR asegurando un ciclo de trabajo del 50% (CCR = ARR / 2).
 * Aplica saturación a 16 bits para los temporizadores TIM3 y TIM13.
 *
 * @param[in,out] htim      Puntero a la estructura de control del periférico TIM_HandleTypeDef.
 * @param[in]     channel   Canal PWM a modular.
 * @param[in]     freq_hz   Frecuencia solicitada en hercios [Hz]. Frecuencias menores a 2 Hz apagan el PWM.
 */
void Stepper_SetSpeed(TIM_HandleTypeDef *htim, uint32_t channel, uint32_t freq_hz) {
    if (freq_hz < 2U) {
        HAL_TIM_PWM_Stop(htim, channel);
        return;
    }

    /* El reloj de los timers APB1 opera al doble de PCLK1 cuando el prescaler APB1 es distinto de 1 */
    const uint32_t timer_clk = HAL_RCC_GetPCLK1Freq() * 2U;
    const uint32_t prescaler = htim->Instance->PSC + 1U;
    const uint32_t div = prescaler * freq_hz;

    if ((div == 0U) || (timer_clk < div)) {
        return;
    }

    uint32_t arr = (timer_clk / div) - 1U;

    /* Saturación estricta para temporizadores de 16 bits (TIM3 y TIM13) */
    if ((htim->Instance == TIM3) || (htim->Instance == TIM13)) {
        if (arr > 65535U) {
            arr = 65535U;
        }
    }

    __HAL_TIM_SET_AUTORELOAD(htim, arr);
    __HAL_TIM_SET_COMPARE(htim, channel, arr / 2U);
}

/**
 * @brief Cómputo del par antagonista estático para mitigar el efecto de la gravedad sobre los eslabones.
 *
 * @param[in] m Puntero al descriptor del motor a compensar.
 * @return float Corrección estática calculada en frecuencia equivalente [Hz].
 */
float computeGravityCompensation(Motor *m) {
    if (m->Kg == 0.0f) {
        return 0.0f;
    }

    const float rad2 = motor2.currentAngle * DEG_TO_RAD_M;
    const float rad3 = motor3.currentAngle * DEG_TO_RAD_M;

    switch (m->id) {
        case 1:
            return 0.0f; /* El eje de cintura es perpendicular a la fuerza de gravedad */
        case 2:
            return m->Kg * cosf(rad2) + (m->Kg * 0.5f) * cosf(rad2 + rad3);
        case 3:
            return m->Kg * cosf(rad2 + rad3);
        default:
            return 0.0f;
    }
}

/**
 * @brief Lazo de control articular para seguimiento continuo de trayectorias y maniobras P2P.
 *
 * @details Conmuta la ley de control según el estado asignado al actuador:
 *  - **Seguimiento Continuo (m->state == TRAJ):**
 *    Aplica control por prealimentación de velocidad más acción proporcional sobre el error de posición:
 *    \f[
 *      v_{cmd} = \dot{q}_{ref} + K_{p\_traj} (q_{ref} - q_{real})
 *    \f]
 *    El término \f$\dot{q}_{ref}\f$ provee el seguimiento nominal dinámico de la trayectoria quíntica,
 *    mientras que el término proporcional corrige las perturbaciones mecánicas y rozamientos.
 *  - **Posicionamiento Discreto (m->state == P2P):**
 *    Aplica control PD con término derivativo calculado a partir de la velocidad real filtrada:
 *    \f[
 *      v_{cmd} = K_p (q_{ref} - q_{real}) - K_d \dot{q}_{filtrada}
 *    \f]
 *
 * La velocidad calculada \f$v_{cmd}\f$ [°/s] se transforma a pulsos por segundo [Hz] en función
 * de la reducción del tren de engranajes y la relación de micropasos (1/8), modulando el registro ARR del timer.
 *
 * @param[in,out] m       Puntero al descriptor del actuador (Motor).
 * @param[in]     q_ref   Ángulo articular de referencia objetivo [°].
 * @param[in]     qd_ref  Velocidad articular feedforward de referencia [°/s].
 * @param[in]     dt      Periodo determinista de muestreo del lazo (0.010 s) [s].
 */
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

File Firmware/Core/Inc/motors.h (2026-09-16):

/**
 * @file motors.h
 * @brief Controlador de bajo nivel para actuadores paso a paso (DRV8825) y lazo cerrado con encoders AS5600.
 * @author Matías Exequiel Molina <matimolina123@gmail.com>
 * @date 2026
 *
 * @details Gestiona la modulación PWM por hardware (TIM2, TIM3, TIM13) y pines de sentido de giro (GPIO).
 * Implementa dos esquemas de control:
 *  - Perfil trapezoidal coordinado multi-eje para movimientos punto a punto (P2P).
 *  - Lazo de seguimiento continuo con prealimentación de velocidad (Feedforward) y realimentación
 *    proporcional (P) de posición para perfiles quínticos interpolados a 100 Hz.
 */

#ifndef MOTORS_H
#define MOTORS_H

#include "main.h"

#ifdef __cplusplus
extern "C" {
#endif

#define ALL_MOTORS_IDLE ((motor1.state == IDLE) && (motor2.state == IDLE) && (motor3.state == IDLE))

/* =========================================================================
 * PARÁMETROS CINEMÁTICOS DE ACCIONAMIENTO (Modo 1/8 Micropaso)
 * ========================================================================= */
#define SPEED_P2P_DEFAULT_HZ  (350.0f)   /**< Velocidad de régimen nominal para traslados P2P [Hz] */
#define MIN_SPEED_HZ          (150.0f)   /**< Frecuencia de despegue inicial para mitigar pérdida de paso [Hz] */
#define MAX_V_HZ              (1000.0f)  /**< Frecuencia máxima absoluta admisible por el hardware [Hz] */
#define MAX_A_HZ_S            (2000.0f)  /**< Rampa máxima de aceleración lineal admisible [Hz/s] */

/**
 * @brief Estados operativos de la máquina de estados de cada eje.
 */
typedef enum {
    IDLE = 0,       /**< Actuador en reposo con bobinas excitadas estáticamente */
    P2P,            /**< Desplazamiento articular punto a punto con perfil trapezoidal */
    TRAJ,           /**< Seguimiento de trayectoria polinómica continua (Feedforward + P) */
    HOMING,         /**< Calibración y búsqueda activa de la referencia articular de origen */
    MOTOR_ERROR     /**< Estado de fallo o enclavamiento por parada de emergencia */
} MotorState_t;
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

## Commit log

2026-09-05 actualizacion de archivos
2026-09-15 Modelo 3d completo
    Modelo 3d completo de la maqueta en formato de solidworks
    [002_mainarm.SLDPRT, 003 VArm.SLDPRT, 004_link 135.SLDPRT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]
2026-09-16 archivos para recolectar objeto que falla pick
    [CuboReceptor.SLDPRT, sujecion.SLDPRT]

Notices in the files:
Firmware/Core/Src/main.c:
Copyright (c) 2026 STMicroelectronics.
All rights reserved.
